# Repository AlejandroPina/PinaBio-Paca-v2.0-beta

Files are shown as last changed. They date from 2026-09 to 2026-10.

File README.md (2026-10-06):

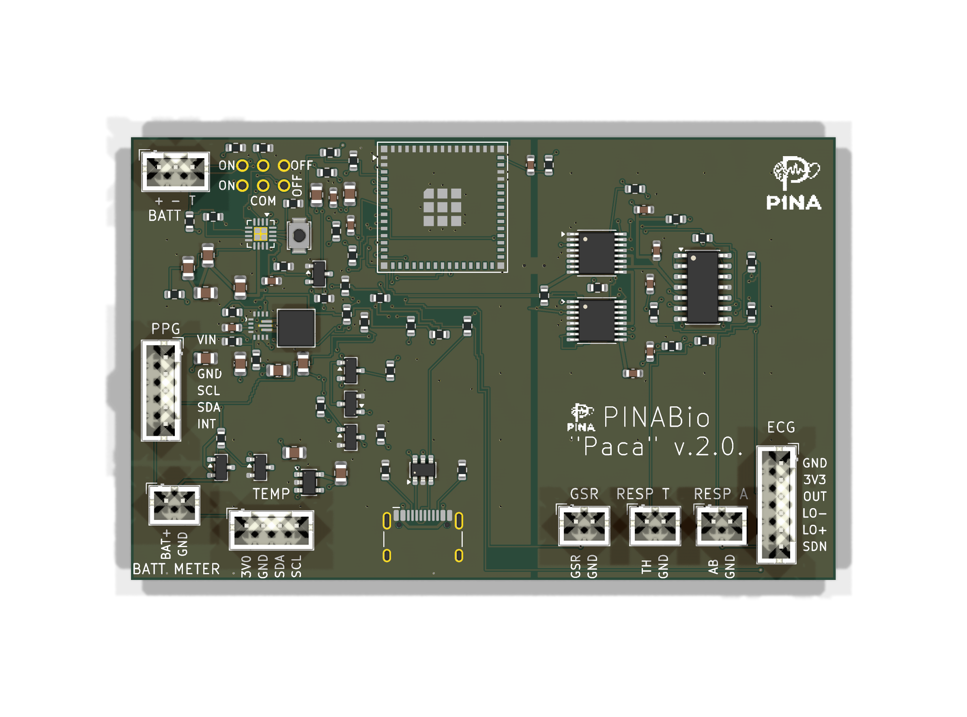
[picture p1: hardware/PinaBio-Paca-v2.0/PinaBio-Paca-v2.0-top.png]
PinaBio Paca v.2.0., cara superior de la PCB


# PinaBio Paca v2.0 beta

[English](README.en.md)

Placa experimental para registrar ECG, pulso óptico (PPG), respuesta galvánica de la piel (GSR), dos bandas de respiración y temperatura, y transmitir los datos por BLE. El uso previsto es investigación y biofeedback; no es un dispositivo médico.

La nueva placa **PINABio "Paca" v.2.0.** se encuentra en [hardware/PinaBio-Paca-v2.0](hardware/PinaBio-Paca-v2.0/README.md). Es un proyecto editable de **KiCad 9.0.9**, con esquemático, PCB de cuatro capas, BOM, Gerbers, taladros y posiciones. Mide **84,50 × 53,11 mm**. KiCad 9.0.9 informa **ERC 0, DRC 0, 0 conexiones pendientes y 0 diferencias entre esquemático y PCB**. Los archivos de fabricación son una salida de prototipo; falta la inspección independiente de huellas y la validación eléctrica de la primera placa ensamblada.

## Qué lleva

- ESP32-S3-MINI-1U-N8 con antena externa U.FL, BLE y Wi-Fi desactivado.
- Dos ADS122C04: uno dedicado al ECG a 600 SPS y otro para GSR, respiración torácica, respiración abdominal y AUX.
- MCP6004, módulo AD8232 externo, módulo GY-MAX30102 externo y módulo CJMCU-30205 externo.
- LiPo protegida de una celda, BQ24074 con power-path, TPS63070 para 3V3_SYS y TLV75530PDBVR a 3,0 V solo para la temperatura.
- Un USB-C soldado en el borde para carga, programación y datos. El interruptor exterior DPDT ON-ON controla el modo del BQ24074 y la habilitación del TPS63070. Con ON y USB, el sistema funciona desde la batería y no carga.
- No hay cortes automáticos en los sensores ni aislamiento USB en la placa. Para adquirir con una persona conectada y USB presente se requiere un aislador USB externo apto para ese uso.

## Documentación

- [Proyecto y conexiones de la PCB](hardware/PinaBio-Paca-v2.0/README.md)
- [Especificación de hardware](docs/es/especificacion.md)
- [Alimentación y USB](docs/es/alimentacion-usb.md)
- [Protocolo y datos](docs/es/protocolo.md)
- [Comparación con V1](docs/es/comparacion-v1.md)

**Antes de encargar montaje:** confirmar orientación y dimensiones del USB-C, TPS63070, todos los conectores y el interruptor cableado; medir los tres módulos externos reales; verificar las transiciones ON/OFF/USB y las tensiones del cargador y reguladores. Los informes de KiCad no sustituyen estas pruebas.

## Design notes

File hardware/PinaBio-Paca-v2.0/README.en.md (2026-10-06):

PinaBio Paca v.2.0. PCB top view

# PINABio "Paca" v.2.0.

[Español](README.md) · [Full specification](../../docs/en/specification.md) · [Power and USB](../../docs/en/power-usb.md)

Editable **KiCad 9.0.9** project, four layers, **84.50 × 53.11 mm**. It implements the project's fixed architecture: one soldered USB-C, physical-switch-controlled BQ24074 standby, no VBUS cut-off MOSFET, two regulators, no automatic sensor disconnects or new I²C pull-ups, two ground regions joined only at NT1, and a copper keepout on all layers beneath the ESP32 U.FL end. The TPS63070 and inductor keep SW_L1 and SW_L2 entirely on F.Cu at 0.40 mm with no vias; the RNM footprint retains pin 1 at top left and counterclockwise numbering.

## Files and checks

- `PinaBio-Paca-v2.0.kicad_sch`, `.kicad_pcb`, `.kicad_pro`: editable schematic and PCB.
- `PinaBio.kicad_sym`, `lib.pretty/`, `sym-lib-table`, `fp-lib-table`: required libraries.
- `bom.csv`: parts list with manufacturer part numbers. L1 is **Coilcraft XAL4020-152MEC**.
- `fab/`: four-layer copper, mask, paste, silkscreen and outline Gerbers; separate PTH/NPTH drill files; `position.csv` in millimetres. `PinaBio-Paca-v2.0-Gerbers.zip` bundles the 14 board and drill files for fabrication upload; BOM and placement are separate.
- `final-erc.txt`, `final-parity.txt`: **ERC 0, DRC 0, 0 unrouted connections and schematic/PCB parity 0**, checked with KiCad 9.0.9.
- `Logo PINA-reducido.jfif`: source image converted to one-colour board silkscreen.

These Gerbers are **prototype outputs**. Before fabrication or assembly, independently check footprints against purchased parts and test one assembled unit, particularly USB-C and TPS63070 orientation, ON/OFF/USB transitions and external-module wiring.

## Connector map

| Ref | Pins in order |
|---|---|
| J1 | HCTL HC-TYPE-C-16P-01A USB-C at lower edge; D+ and D− via USBLC6-2SC6 and 22 Ω series resistors. |
| J2 BATT | 1 protected BAT+, 2 GND, 3 TS/NTC. Three-pin JST PH. The silkscreen says “BATT” below the connector. |
| J3 ECG | 1 AGND, 2 3V3_A, 3 ECG_OUT, 4 LO_N, 5 LO_P, 6 3V3_A (SDN permanently enabled). Matches the red module order GND, 3.3V, OUTPUT, LO−, LO+, SDN. |
| J4 PPG | 1 3V3_SYS/VIN, 2 GND, 3 SCL, 4 SDA, 5 INT. “VIN” identifies module power; the other four signals are labelled by their pins. |
| J5 TEMP | 1 3V0_TEMP, 2 GND, 3 SDA, 4 SCL. Four-pin JST PH; tie A0/A1/A2 to GND on the CJMCU-30205 module. |
| J6 GSR | 1 GSR signal, 2 AGND. |
| J7 RESP T | 1 chest signal, 2 AGND. |
| J8 RESP A | 1 abdominal signal, 2 AGND. |
| J9 BATT METER | 1 switched BAT+, 2 GND. JST PH B2B-PH-K-S(LF)(SN), reserved for the battery meter. |

J9 is live only while **3V3_SYS** is active (ON with battery, or OFF with USB). Q4 BSS84 and Q5 BSS138 form the high-side switch; Q4 has 1 MΩ gate-to-source. J9 is not a general power output.

## Switch and power

SW1 is **six cable holes**, not a footprint for soldering the switch. The reference panel part is C&K **7201SYZQE**, DPDT ON-ON. Another six-terminal DPDT ON-ON part, such as an MTS-202, may be used after checking its common terminals and contact states with a meter. Hole 1–6 numbering follows C&K terminal 1–6: 1 VLOG, 2 EN2_CE, 3 GND, 4 BAT_PROT, 5 TPS_EN, 6 VLOG.

R39, **10 kΩ, 1 %**, sits close to TPS63070 EN, between TPS_EN and TPS_EN_IC. R12, 100 kΩ, stays on the switch side. PS/SYNC is tied to ground for forced PWM. TLV75530PDBVR supplies **only** the temperature module at 3.0 V. VBUS link R3 remains **0 Ω**.

With OFF and USB attached, the battery charges and the board may be programmed. With ON and USB attached, BQ24074 is in standby: the LiPo runs the board, USB carries data, and charging stops. A suitable external USB isolator is required before connecting a person in that state. The PCB has no onboard isolation or automatic sensor disconnect.

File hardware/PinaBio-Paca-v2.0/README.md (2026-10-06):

PCB PinaBio Paca v.2.0., cara superior

# PINABio "Paca" v.2.0.

[English](README.en.md) · [Especificación completa](../../docs/es/especificacion.md) · [Alimentación y USB](../../docs/es/alimentacion-usb.md)

Proyecto editable de **KiCad 9.0.9**, cuatro capas, **84,50 × 53,11 mm**. Implementa la arquitectura cerrada del proyecto: un USB-C soldado, BQ24074 en standby mediante interruptor exterior, sin MOSFET de corte de VBUS, dos reguladores, sin cortes automáticos de sensores ni pull-ups nuevos de I²C, dos masas unidas solo en NT1 y keepout de cobre en todas las capas bajo el extremo U.FL del ESP32. La zona del TPS63070 y la bobina mantiene los nodos SW_L1 y SW_L2 en F.Cu, 0,40 mm y sin vías; la huella RNM conserva el pin 1 arriba a la izquierda y la numeración antihoraria.

## Archivos y verificación

- `PinaBio-Paca-v2.0.kicad_sch`, `.kicad_pcb` y `.kicad_pro`: esquemático y PCB.
- `PinaBio.kicad_sym`, `lib.pretty/`, `sym-lib-table` y `fp-lib-table`: bibliotecas necesarias.
- `bom.csv`: lista de materiales con MPN. L1 es **Coilcraft XAL4020-152MEC**.
- `fab/`: Gerbers de las cuatro capas, máscaras, pasta, serigrafía, contorno, taladros PTH/NPTH y `position.csv` en milímetros. `PinaBio-Paca-v2.0-Gerbers.zip` agrupa los 14 archivos de placa y taladro para subirlos al fabricante; BOM y posiciones se entregan por separado.
- `final-erc.txt` y `final-parity.txt`: **ERC 0, DRC 0, 0 sin conectar y paridad esquema-PCB 0**, ejecutados con KiCad 9.0.9.
- `Logo PINA-reducido.jfif`: imagen fuente del logo que se convirtió a serigrafía monocroma.

Los Gerbers son **de prototipo**. Antes de fabricar o montar, otra persona debe cotejar las huellas con los componentes comprados y ensayar una primera unidad, en especial la orientación del USB-C y TPS63070, las transiciones ON/OFF/USB y el cableado de los módulos externos.

## Conectores

| Referencia | Conexión por orden de pin |
|---|---|
| J1 | USB-C HCTL HC-TYPE-C-16P-01A, boca en el borde inferior; D+ y D− pasan por USBLC6-2SC6 y resistencias de 22 Ω. |
| J2 BATT | 1 BAT+ protegido, 2 GND, 3 TS/NTC. JST PH de 3 pines. La serigrafía usa «BATT» debajo del conector. |
| J3 ECG | 1 AGND, 2 3V3_A, 3 ECG_OUT, 4 LO_N, 5 LO_P, 6 3V3_A (SDN permanentemente habilitado). Orden del módulo rojo: GND, 3.3V, OUTPUT, LO−, LO+, SDN. |
| J4 PPG | 1 3V3_SYS/VIN, 2 GND, 3 SCL, 4 SDA, 5 INT. «VIN» identifica la alimentación del módulo; las otras cuatro señales están rotuladas junto a sus pines. |
| J5 TEMP | 1 3V0_TEMP, 2 GND, 3 SDA, 4 SCL. JST PH de 4 pines; unir A0/A1/A2 a GND en el módulo CJMCU-30205. |
| J6 GSR | 1 señal GSR, 2 AGND. |
| J7 RESP T | 1 señal torácica, 2 AGND. |
| J8 RESP A | 1 señal abdominal, 2 AGND. |
| J9 BATT METER | 1 BAT+ conmutado por Q4 BSS84/Q5 BSS138, 2 GND. JST PH B2B-PH-K-S(LF)(SN), reservado para el medidor de batería. |

J9 solo entrega tensión cuando está activo **3V3_SYS** (ON con batería u OFF con USB). Q4 tiene una resistencia de 1 MΩ entre puerta y fuente. La alimentación del medidor procede de BAT_PROT y no está destinada a alimentar otros módulos.

## Interruptor y alimentación

SW1 son **seis taladros para cable**, no una huella para soldar el interruptor. La pieza de referencia en la caja es C&K **7201SYZQE**, DPDT ON-ON. Puede emplearse otro DPDT ON-ON de seis terminales, como un MTS-202, después de verificar con multímetro sus comunes y contactos. Taladros 1–6 corresponden a terminales 1–6 de la referencia C&K: 1 VLOG, 2 EN2_CE, 3 GND, 4 BAT_PROT, 5 TPS_EN y 6 VLOG.

R39 de **10 kΩ, 1 %**, junto al pin EN del TPS63070, separa TPS_EN de TPS_EN_IC. R12 de 100 kΩ queda al lado del interruptor. PS/SYNC va a masa para PWM forzado. El TLV75530PDBVR alimenta **solo** el módulo de temperatura a 3,0 V; R3 de VBUS continúa en **0 Ω**.

Con OFF y USB se carga la batería y la placa puede programarse. Con ON y USB el BQ24074 está en standby: el sistema se alimenta de la LiPo, USB lleva datos y la batería no carga. Para conectar a una persona en ese modo se exige un aislador USB externo apropiado. No hay aislador ni desconexión automática de sensores en la PCB.

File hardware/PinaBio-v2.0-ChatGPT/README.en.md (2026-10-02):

PinaBio Paca v.2.0. PCB top view

# PINABio "Paca" v.2.0. — ChatGPT board

[Español](README.md) · [Full specification](../../docs/en/specification.md) · [Power and USB](../../docs/en/power-usb.md)

Editable **KiCad 9.0.9** project, four layers, **84.50 × 53.11 mm**. Derived from the Cursor implementation while retaining its fixed architecture: one soldered USB-C, physical-switch-controlled BQ24074 standby, no VBUS cut-off MOSFET, two regulators, no automatic sensor disconnects or new I²C pull-ups, two ground regions joined only at NT1, and a copper keepout on all layers beneath the ESP32 U.FL end. The TPS63070 and inductor keep SW_L1 and SW_L2 entirely on F.Cu at 0.40 mm with no vias; the RNM footprint retains pin 1 at top left and counterclockwise numbering.

## Files and checks

- `PinaBio-v2.0-ChatGPT.kicad_sch`, `.kicad_pcb`, `.kicad_pro`: editable schematic and PCB.
- `PinaCursor.kicad_sym`, `lib.pretty/`, `sym-lib-table`, `fp-lib-table`: required libraries.
- `bom.csv`: parts list with manufacturer part numbers. L1 is **Coilcraft XAL4020-152MEC**.
- `fab/`: four-layer copper, mask, paste, silkscreen and outline Gerbers; separate PTH/NPTH drill files; `position.csv` in millimetres. `PinaBio-v2.0-ChatGPT-Gerbers.zip` bundles the 14 board and drill files for fabrication upload; BOM and placement are separate.
- `final-erc.txt`, `final-parity.txt`: **ERC 0, DRC 0, 0 unrouted connections and schematic/PCB parity 0**, checked with KiCad 9.0.9.
- `Logo PINA-reducido.jfif`: source image converted to one-colour board silkscreen.

These Gerbers are **prototype outputs**. Before fabrication or assembly, independently check footprints against purchased parts and test one assembled unit, particularly USB-C and TPS63070 orientation, ON/OFF/USB transitions and external-module wiring.

## Connector map

| Ref | Pins in order |
|---|---|
| J1 | HCTL HC-TYPE-C-16P-01A USB-C at lower edge; D+ and D− via USBLC6-2SC6 and 22 Ω series resistors. |
| J2 BATT | 1 protected BAT+, 2 GND, 3 TS/NTC. Three-pin JST PH. The silkscreen says “BATT” below the connector. |
| J3 ECG | 1 AGND, 2 3V3_A, 3 ECG_OUT, 4 LO_N, 5 LO_P, 6 3V3_A (SDN permanently enabled). Matches the red module order GND, 3.3V, OUTPUT, LO−, LO+, SDN. |
| J4 PPG | 1 3V3_SYS/VIN, 2 GND, 3 SCL, 4 SDA, 5 INT. “VIN” identifies module power; the other four signals are labelled by their pins. |
| J5 TEMP | 1 3V0_TEMP, 2 GND, 3 SDA, 4 SCL. Four-pin JST PH; tie A0/A1/A2 to GND on the CJMCU-30205 module. |
| J6 GSR | 1 GSR signal, 2 AGND. |
| J7 RESP T | 1 chest signal, 2 AGND. |
| J8 RESP A | 1 abdominal signal, 2 AGND. |
| J9 BATT METER | 1 switched BAT+, 2 GND. JST PH B2B-PH-K-S(LF)(SN), for a meter drawing only tens of mA. |

J9 is live only while **3V3_SYS** is active (ON with battery, or OFF with USB). Q4 BSS84 and Q5 BSS138 form the high-side switch; Q4 has 1 MΩ gate-to-source. J9 is not a general power output.

## Switch and power

SW1 is **six cable holes**, not a footprint for soldering the switch. The reference panel part is C&K **7201SYZQE**, DPDT ON-ON. Another six-terminal DPDT ON-ON part, such as an MTS-202, may be used after checking its common terminals and contact states with a meter. Hole 1–6 numbering follows C&K terminal 1–6: 1 VLOG, 2 EN2_CE, 3 GND, 4 BAT_PROT, 5 TPS_EN, 6 VLOG.

R39, **10 kΩ, 1 %**, sits close to TPS63070 EN, between TPS_EN and TPS_EN_IC. R12, 100 kΩ, stays on the switch side. PS/SYNC is tied to ground for forced PWM. TLV75530PDBVR supplies **only** the temperature module at 3.0 V. VBUS link R3 remains **0 Ω**.

With OFF and USB attached, the battery charges and the board may be programmed. With ON and USB attached, BQ24074 is in standby: the LiPo runs the board, USB carries data, and charging stops. A suitable external USB isolator is required before connecting a person in that state. The PCB has no onboard isolation or automatic sensor disconnect.

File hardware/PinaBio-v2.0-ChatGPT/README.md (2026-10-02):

PCB PinaBio Paca v.2.0., cara superior

# PINABio "Paca" v.2.0. — placa ChatGPT

[English](README.en.md) · [Especificación completa](../../docs/es/especificacion.md) · [Alimentación y USB](../../docs/es/alimentacion-usb.md)

Proyecto editable de **KiCad 9.0.9**, cuatro capas, **84,50 × 53,11 mm**. Deriva de la implementación de Cursor y conserva su arquitectura: un USB-C soldado, BQ24074 en standby mediante interruptor exterior, sin MOSFET de corte de VBUS, dos reguladores, sin cortes automáticos de sensores ni pull-ups nuevos de I²C, dos masas unidas solo en NT1 y keepout de cobre en todas las capas bajo el extremo U.FL del ESP32. La zona del TPS63070 y la bobina mantiene los nodos SW_L1 y SW_L2 en F.Cu, 0,40 mm y sin vías; la huella RNM conserva el pin 1 arriba a la izquierda y la numeración antihoraria.

## Archivos y verificación

- `PinaBio-v2.0-ChatGPT.kicad_sch`, `.kicad_pcb` y `.kicad_pro`: esquemático y PCB.
- `PinaCursor.kicad_sym`, `lib.pretty/`, `sym-lib-table` y `fp-lib-table`: bibliotecas necesarias.
- `bom.csv`: lista de materiales con MPN. L1 es **Coilcraft XAL4020-152MEC**.
- `fab/`: Gerbers de las cuatro capas, máscaras, pasta, serigrafía, contorno, taladros PTH/NPTH y `position.csv` en milímetros. `PinaBio-v2.0-ChatGPT-Gerbers.zip` agrupa los 14 archivos de placa y taladro para subirlos al fabricante; BOM y posiciones se entregan por separado.
- `final-erc.txt` y `final-parity.txt`: **ERC 0, DRC 0, 0 sin conectar y paridad esquema-PCB 0**, ejecutados con KiCad 9.0.9.
- `Logo PINA-reducido.jfif`: imagen fuente del logo que se convirtió a serigrafía monocroma.

Los Gerbers son **de prototipo**. Antes de fabricar o montar, otra persona debe cotejar las huellas con los componentes comprados y ensayar una primera unidad, en especial la orientación del USB-C y TPS63070, las transiciones ON/OFF/USB y el cableado de los módulos externos.

## Conectores

| Referencia | Conexión por orden de pin |
|---|---|
| J1 | USB-C HCTL HC-TYPE-C-16P-01A, boca en el borde inferior; D+ y D− pasan por USBLC6-2SC6 y resistencias de 22 Ω. |
| J2 BATT | 1 BAT+ protegido, 2 GND, 3 TS/NTC. JST PH de 3 pines. La serigrafía usa «BATT» debajo del conector. |
| J3 ECG | 1 AGND, 2 3V3_A, 3 ECG_OUT, 4 LO_N, 5 LO_P, 6 3V3_A (SDN permanentemente habilitado). Orden del módulo rojo: GND, 3.3V, OUTPUT, LO−, LO+, SDN. |
| J4 PPG | 1 3V3_SYS/VIN, 2 GND, 3 SCL, 4 SDA, 5 INT. «VIN» identifica la alimentación del módulo; las otras cuatro señales están rotuladas junto a sus pines. |
| J5 TEMP | 1 3V0_TEMP, 2 GND, 3 SDA, 4 SCL. JST PH de 4 pines; unir A0/A1/A2 a GND en el módulo CJMCU-30205. |
| J6 GSR | 1 señal GSR, 2 AGND. |
| J7 RESP T | 1 señal torácica, 2 AGND. |
| J8 RESP A | 1 señal abdominal, 2 AGND. |
| J9 BATT METER | 1 BAT+ conmutado por Q4 BSS84/Q5 BSS138, 2 GND. JST PH B2B-PH-K-S(LF)(SN), solo para medidor de unas decenas de mA. |

J9 solo entrega tensión cuando está activo **3V3_SYS** (ON con batería u OFF con USB). Q4 tiene una resistencia de 1 MΩ entre puerta y fuente. La alimentación del medidor procede de BAT_PROT y no está destinada a alimentar otros módulos.

## Interruptor y alimentación

SW1 son **seis taladros para cable**, no una huella para soldar el interruptor. La pieza de referencia en la caja es C&K **7201SYZQE**, DPDT ON-ON. Puede emplearse otro DPDT ON-ON de seis terminales, como un MTS-202, después de verificar con multímetro sus comunes y contactos. Taladros 1–6 corresponden a terminales 1–6 de la referencia C&K: 1 VLOG, 2 EN2_CE, 3 GND, 4 BAT_PROT, 5 TPS_EN y 6 VLOG.

R39 de **10 kΩ, 1 %**, junto al pin EN del TPS63070, separa TPS_EN de TPS_EN_IC. R12 de 100 kΩ queda al lado del interruptor. PS/SYNC va a masa para PWM forzado. El TLV75530PDBVR alimenta **solo** el módulo de temperatura a 3,0 V; R3 de VBUS continúa en **0 Ω**.

Con OFF y USB se carga la batería y la placa puede programarse. Con ON y USB el BQ24074 está en standby: el sistema se alimenta de la LiPo, USB lleva datos y la batería no carga. Para conectar a una persona en ese modo se exige un aislador USB externo apropiado. No hay aislador ni desconexión automática de sensores en la PCB.

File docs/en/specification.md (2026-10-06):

# PinaBio Paca v2.0 beta — hardware specification `SPEC-0.9`

This design specification now has a KiCad 9.0.9 prototype implementation. ERC, DRC and schematic/PCB parity are zero; independent footprint review and tests on an assembled board are still required. PinaBio is for experimental research and biofeedback, not medical use or diagnosis.

## Scope and power architecture

The ESP32-S3-MINI-1U-N8 acquires ECG, PPG, GSR, thoracic and abdominal respiration bands, local temperature and battery voltage, then sends raw data over BLE with Wi‑Fi disabled. One ADS122C04 is dedicated to ECG; the other serves GSR and both bands. MAX30102 and MAX30205 are external I²C modules.

LiPo 1S protected → BQ24074 → TPS63070 → nominal 3.295 V `3V3_SYS` (49.9 kΩ / 16.0 kΩ, 0.1 %, forced PWM). An initially 0 Ω link may feed a `3V3_A` analogue island. A TLV75530PDBVR makes `3V0_TEMP` only for the CJMCU-30205, with 2.2 µF X7R 0805 at input and output. There is **no 2.9 V rail, TPS7A20 or TCA9801**.

## USB, switch and body connections

USB-C is a USB 2.0 sink: CC1/CC2 have 5.1 kΩ Rd resistors. D+ and D− pass through a USBLC6-2SC6 in SOT-23-6 (the same pinout as the USBLC6-2P6: connector on one side, ESP32 on the other, GND and VBUS as on that symbol) and then through 22 Ω in series: D− to GPIO19 and D+ to GPIO20. Protected VBUS reaches BQ24074 IN in both switch positions. There is no external VBUS-cutoff MOSFET. The physical switch sets the charger mode pins and regulator enable independently of the ESP32.

The switch is not on the board: it mounts in the enclosure. The part is a C&K 7201SYZQE (7000 series, DPDT, two maintained ON-ON positions, threaded panel bushing, six solder-lug terminals). It is not momentary, not a three-position switch, and it is not the JS202011JCQN. The datasheet is *7000 Series Miniature Toggle Switches* ([PDF](https://media.digikey.com/pdf/Data%20Sheets/C&K/7000%20Mini%20Toggle%20Series.pdf)); the DPDT figure on page 2 names 7201SYZQE. The code reads: 7201 = DP On-None-On, S = 0.420 in actuator, Y = 0.350 in bushing with keyway and 1/4-40 thread, Z = six solder lugs, Q = contact material, E = epoxy seal. Commons are terminals 2 and 5. ON is the lever away from the keyway (datasheet position 3): it closes 2-1 and 5-4. OFF is the lever toward the keyway (position 1): it closes 2-3 and 5-6. The cable is one-to-one: board pad 1 `VLOG` to terminal 1, pad 2 `EN2_CE` to terminal 2, pad 3 `GND` to terminal 3, pad 4 `BAT_PROT` to terminal 4, pad 5 `TPS_EN` to terminal 5, and pad 6 `VLOG` to terminal 6. ON therefore ties `EN2_CE` to `VLOG` and `TPS_EN` to `BAT_PROT`; OFF ties `EN2_CE` to `GND` and `TPS_EN` to `VLOG`. The six board holes have no orderable code; the code belongs to the enclosure switch.

With OFF and valid VBUS, `EN1=high`, `EN2=low` and `CE=low` allow charging and USB-powered OUT; USB500 is permitted only when the source supports that current. With ON and valid VBUS, `EN1=EN2=high` select standby/USB suspend: internal `Q1` (IN→OUT) is open, `Q2` (BAT→OUT) is closed and charging stops. `CE=high` adds charge inhibition but cannot alone prevent USB from powering OUT. EN1, EN2 and CE must be driven by the physical switch and VBUS, remain defined with no battery, and never rely on firmware. ILIM, ISET and ITERM are sized for the actual USB source, cell and initial ≈300 mA charge target. TMR is 46.4 kΩ, 1 %, to ground. TS connects to the cell NTC. GPIO0 is reserved for BOOT, with a 10 kΩ pull-up to `3V3_SYS`; the BOOT button takes it to ground.

The VBUS-derived logic must meet these limits at each EN1, EN2 and CE pin: low **0–0.4 V**, high **1.4–6 V**, absolute maximum **−0.3 to 7 V**, including transients. The schematic must provide the necessary voltage limiting/protection and operating margin below 6 V; 7 V is not a design target. The higher voltage tolerance at IN does not extend to these pins. See [power and USB](power-usb.md).

The TPS63070 hardware enable must implement `(OFF and valid VBUS) or (ON and valid battery)`. This permits OFF+USB programming without a battery while preventing ON+USB from starting without one. The schematic must define the battery-valid condition and verify source transitions on an ON→OFF switch movement. [TI BQ24074 datasheet](https://www.ti.com/lit/ds/symlink/bq24074.pdf), Table 7-2 and Section 9.3.2.

| Switch | USB | BQ24074 mode | Board source | LiPo charge | USB data | Person-connected use |
|---|---:|---|---|---|---|---|
| OFF | no | invalid input | none | no | no | no acquisition |
| OFF | yes | USB500 if source permits | USB through BQ24074 | yes | yes, programming | no person connected |
| ON | no | invalid input | LiPo | no | no | battery acquisition |
| ON | yes | standby, `EN1=EN2=high` | LiPo | no | yes | external USB isolator required |

With OFF, USB powers the ESP for programming and charges the cell; removing USB powers the board down. With ON, D+/D− remain available and OUT is battery powered even though VBUS remains at charger IN. ECG, PPG, temperature, GSR and respiration connectors connect directly to their respective front ends, without automatic cutoff relays or switches. OFF+USB can therefore energize sensor connectors; direct-USB charging and programming require removing all sensors from the person.

An external host-powered USB isolator is mandatory for use with a person while USB is connected. The board USB ground is not cut; isolation belongs in the external cable. Firmware can report USB presence but cannot prove that an isolator is fitted. A normal USB cable must not be used on a person.

## Acquisition front ends

| Signal | Implementation and initial configuration |
|---|---|
| ECG | External AD8232, dedicated ADS122C04, internal 2.048 V reference, PGA bypass, gain 1, 600 SPS. Divider: 33.2 kΩ from OUTPUT and 47.5 kΩ to ground, 1 %. At a 3.30 V full-scale output the ADC sees 1.94 V; at 3.40 V it sees 2.00 V, under the 2.048 V reference. Do not use 20.0/40.2 kΩ. Measure the real swing to confirm the module does not clip before the divider. A divider cannot repair an OUTPUT that is already clipped. |
| GSR | MCP6004-buffered ≈0.50 V excitation; a physical 100 kΩ series resistor limits normal short-circuit current to ≈5 µA. |
| Thorax / abdomen | One identical buffered front end each; measure real band ranges before freezing 100 kΩ and filters. |
| PPG | External MAX30102/GY-30102, 3.3 V, I²C plus INT; validate its actual regulators, pull-ups, LED current and voltage levels. |
| Temperature | CJMCU-30205 from `3V0_TEMP` only, on a 4-pin connector (3V0_TEMP, GND, SDA, SCL). Module VCC ties straight to the chip. A0, A1 and A2 of the module are tied to GND on the module itself (solder or a short wire), not through the cable, and set address 0x48. The module's OS is left unconnected (the module carries its own 10 kΩ pull-up). |

The slow ADS initially samples GSR, thorax and abdomen at 20 SPS each. Report OPEN, SHORT, OUT_OF_RANGE and UNCALIBRATED rather than false values. Bands provide resistance and a derived respiratory curve, not lung volume. ADS IDACs remain disabled and never connect to body paths.

## Board

Four layers. The board is **84.50 × 53.11 mm**; the width leaves room for J3 labels outside the connector. USB-C is at the lower edge with its mouth extending past the outline. The ESP32-S3-MINI-1U has no printed antenna: it has a U.FL connector. That end of the module sits at the upper board edge, as far out as it will go, so the external antenna is outside the copper. On every layer, under that end and a little past the module edge outward, there is no copper, no track, no via and no plane. USB and the buck do not sit under that zone.

There are two ground planes. Digital ground covers the ESP32, USB, the BQ24074 and the TPS63070. Analogue ground covers the ADS122C04 devices, the MCP6004, the ECG divider, GSR and the bands. They join in one place, short and wide, next to the ADCs and the 0 Ω link between `3V3_SYS` and `3V3_A`, so the supply and the return meet at the same point. There are no extra joins and no thin track crossing the board. Analogue signals do not cross digital ground. In1 is ground, split into those two zones. F.Cu carries the same split, stitched with vias to its own zone. In2 is `3V3_SYS` and carries no data signals. B.Cu carries the signals.

Both TPS63070 inductor nodes stay on F.Cu, with no via, at 0.40 mm for the whole run.

## Mandatory verification

Measure every breakout; test all four USB/switch states including no battery; prove ON+USB leaves OUT on BAT with zero charge current and VBUS/D+/D− cannot back-power ON-without-battery. Capture EN1, EN2 and CE during steady states and switch/USB transients to check their voltage limits. With OFF+USB, document voltage at the sensor connectors. Measure 3.3 V ripple and load, GSR fault current, ECG range/noise, external buses and USB-isolator behaviour. KiCad 9.0.9 schematic, PCB, BOM, Gerbers, drill and placement outputs exist with ERC, DRC and schematic/PCB parity at zero. Footprint checks, body-connected-path review and these bench results remain necessary before a production order.

## Implementation contract

- J3, external AD8232 module: pin 1 AGND/GND, 2 3V3_A/3.3V, 3 ECG_OUT/OUTPUT, 4 LO_N/LO−, 5 LO_P/LO+, 6 3V3_A/SDN. SDN remains enabled. This matches the red module order for a flat cable.
- J5, CJMCU-30205: pin 1 3V0_TEMP, 2 GND, 3 SDA, 4 SCL. J9 battery meter: JST PH B2B-PH-K-S(LF)(SN), pin 1 switched BAT+, pin 2 GND. A BSS84LT1G high-side device and BSS138LT1G enable it only while 3V3_SYS exists; 1 MΩ ties the BSS84 gate to its source. J9 is reserved for the battery meter.
- R39, YAGEO RC0603FR-0710KL, 10 kΩ 1 %, is in series between TPS_EN and TPS63070 EN, close to the IC. The 100 kΩ R12 pulldown remains on the switch side. PS/SYNC stays grounded. R3 remains 0 Ω.
- L1 is Coilcraft **XAL4020-152MEC**, 1.5 µH with the unchanged XAL4020 footprint; “C” denotes 7-inch reel packaging.
- J3 silkscreen labels form one column outside and aligned with its six pins. The PINA logo remains at the upper right, with a smaller copy beside the two-line “PINABio \"Paca\" v.2.0.” board name at centre right. J2 is marked BATT; J4's VIN, GND, SCL, SDA and INT labels share one left alignment. Connector names and pin labels are at least 1.0 mm high with 0.15 mm stroke.

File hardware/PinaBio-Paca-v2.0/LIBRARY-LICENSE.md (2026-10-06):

The project uses official KiCad symbols and footprints under the [KiCad library license](https://www.kicad.org/libraries/license/). The local `PinaBio.kicad_sym` and `lib.pretty/` contain project-specific ADS122C04/TPS63070 symbols and TPS63070, switch-hole and ground-tie footprints derived from the manufacturers' package and pinout drawings. Check those footprints against the purchased parts before assembly.

The optional `3dmodels/ESP32-S3-MINI-1U.STEP` model was copied from the [Espressif KiCad libraries](https://github.com/espressif/kicad-libraries), licensed CC-BY-SA 4.0 with the electronics-design waiver in the upstream LICENSE.md.

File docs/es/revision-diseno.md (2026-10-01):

# Revisión de diseño — 1 de octubre de 2026

La revisión `SPEC-0.9` / `PWR-0.7` mantiene las decisiones de `SPEC-0.8` y añade el USB, el temporizador del cargador, la antena U.FL y la masa partida. Siguen vigentes los límites de tensión y ensayos de `EN1`, `EN2` y `CE` del BQ24074.

1. El TPS63070 queda a 3,295 V (49,9 kΩ / 16,0 kΩ, 0,1 %, PWM forzado). Un TLV75530PDBVR hace 3,0 V solo para el CJMCU-30205, cuyo VCC entra directo al chip, con 2,2 µF X7R en entrada y salida. No hay raíl de 2,9 V ni TCA9801.
2. OFF permite carga y programación desde USB. Los conectores de sensores no se cortan; se retiran de la persona antes de usar USB directo.
3. ON con USB pone `EN1=EN2=alto` y `CE=alto`: el BQ24074 abre internamente IN→OUT, mantiene BAT→OUT, detiene la carga y conserva D+/D− para datos/programación. VBUS permanece en `IN`; la placa se alimenta de batería.
4. No hay barrera de contactos ni corte automático por VBUS: la adquisición con USB y una persona solo se admite usando un aislador externo alimentado desde el host. La placa informa presencia USB, pero no puede certificar el aislador.
5. El divisor del ECG es 33,2 kΩ desde OUTPUT y 47,5 kΩ a masa, al 1 %. A 3,40 V de salida plena el ADS ve 2,00 V, por debajo de 2,048 V. La medida comprueba que el módulo no recorta antes del divisor.
6. GSR y las bandas conservan excitación ≈0,50 V y 100 kΩ físicamente en serie, con corriente de corto ≈5 µA.
7. El interruptor físico determina los niveles de `EN1`, `EN2`, `CE` y la habilitación del TPS63070, sin firmware y aun sin batería. OFF+USB debe poder programar; ON+USB sin batería no debe arrancar.
8. `EN1`, `EN2` y `CE` tienen alto funcional de 1,4–6 V, bajo de 0–0,4 V y máximo absoluto de −0,3 a 7 V. El esquema debe proteger estas entradas frente a VBUS y sus transitorios; 7 V no es un valor de operación.
9. D− (GPIO19) y D+ (GPIO20) llevan 22 Ω en serie entre un USBLC6-2SC6 (SOT-23-6) y el ESP32. GPIO0 lleva 10 kΩ a `3V3_SYS` y el pulsador de BOOT lo pone a masa. `TMR` del BQ24074 lleva 46,4 kΩ al 1 % a masa. Los 2,2 µF del TLV75530 son X7R 0805.
10. El ESP32-S3-MINI-1U lleva conector U.FL, no antena impresa. Ese extremo queda en el borde. Bajo él, en todas las capas y un poco más allá del módulo, no hay cobre, pistas, vías ni plano. El USB y el buck no van bajo esa zona.
11. Masa digital (ESP32, USB, BQ24074, TPS63070) y masa analógica (ADS122C04, MCP6004, divisor de ECG, GSR y bandas) se unen en un solo punto, corto y ancho, junto a los ADS y al puente de 0 Ω entre `3V3_SYS` y `3V3_A`. Las señales analógicas no cruzan la masa digital. In1 es esa masa partida; In2 es `3V3_SYS` sin señales de datos. Los dos nodos del inductor del TPS63070 van en F.Cu, sin vía, a 0,40 mm.

Quedan pendientes para el esquema y prototipo: polarización y secuencia de los pines de modo del BQ24074, presupuesto de corriente de los módulos, compatibilidad real de sus niveles eléctricos y pruebas del aislador externo. Ningún documento autoriza fabricar hasta superar los ensayos listados en `especificacion.md`.

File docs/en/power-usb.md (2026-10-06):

# Power and USB — revision `PWR-0.7`

[Home](../../README.en.md) · [Hardware specification](specification.md)

One USB-C connector, a protected 1S LiPo, a BQ24074 power path and a TPS63070 at 3.295 V. A TLV75530PDBVR makes 3.0 V only for the CJMCU-30205. The physical switch controls the BQ24074 mode and the regulator enable; firmware does not choose the charging or system power source.

With **OFF and USB**, `EN1=high`, `EN2=low` and `CE=low` select USB500 mode. Valid `IN` powers `OUT` and charges the cell; TPS63070 can power the ESP32 for programming. Sensor connectors are not automatically disconnected; remove sensors from the person before charging or programming with direct USB. Select the 500 mA input limit only when the USB source permits it. The initial battery-charge target is about 300 mA; measure the simultaneous system load during programming.

With **ON and USB**, `EN1=EN2=high` select standby/USB suspend. TI specifies that internal `Q1` (IN→OUT) is off and `Q2` (BAT→OUT) is on: the battery powers the board and charging stops. `CE=high` adds charge inhibition but cannot replace standby because CE alone leaves USB-powered OUT active. VBUS remains at the charger's `IN` pin; “battery only” describes the source of OUT and the board, not a physically unpowered USB connector or charger. Native D+/D− remain available for programming and data.

Without USB, IN is invalid and OUT follows the battery. ON enables TPS63070; OFF disables it. Any USB acquisition with a person connected requires an external host-powered isolator that separates data, ground and power and supplies the appropriate VBUS on the board side.

| Switch | USB | `EN1/EN2/CE` with valid VBUS | OUT source | Charge | ESP32 | Person-connected use |
|---|---|---|---|---|---|---|
| OFF | no | biased low; invalid input | battery, system load disabled | no | off | no acquisition |
| OFF | yes | high/low/low | USB | yes | on for maintenance | no person connected |
| ON | no | invalid input | battery | no | on | battery acquisition |
| ON | yes | high/high/high | battery | no | on, USB data | external isolator required |

## Hardware requirements

- Protected VBUS connects to BQ24074 IN in both switch positions. **Do not fit the external VBUS-cutoff MOSFET.** Place the IN and OUT capacitors required by TI.
- EN1 must be high when VBUS is valid. EN2 and CE must be high with ON and VBUS, low with OFF and VBUS. The physical switch and bias network must establish these levels without the ESP32 or battery; no control input may float. Verify levels and sequencing when USB is inserted and the switch moves.
- For EN1, EN2 and CE, TI specifies a **1.4–6 V** high level, a **0–0.4 V** low level and an **−0.3 to 7 V** absolute-maximum range. The 7 V limit is not a design target. The network deriving these signals from VBUS must limit their voltage during normal operation, insertion and foreseeable overvoltage, with margin below 6 V; do not connect raw VBUS directly without demonstrating compliance. The IN pin has a different, higher absolute maximum that does not protect the logic pins.
- With ON, USB and no battery, standby must prevent OUT from powering the board from USB. The regulator must not start without a valid battery. With OFF, USB and no battery, programming may start.
- Select ILIM, ISET, ITERM and TS for the actual USB source, cell and NTC. TMR is 46.4 kΩ, 1 %, to ground. BQ24074 has no SYSOFF pin and does not replace cell protection.
- No sensor-connector cutoff relays or switches are fitted. OFF+USB may power those connectors from VBUS, so direct-USB charging and programming require all sensors to be removed from the person. ON+USB with a person requires a host-powered external isolator.
- TPS63070 runs in forced PWM. Feedback divider: 49.9 kΩ from VOUT to FB and 16.0 kΩ from FB to ground, both 0.1 %. Setpoint 3.295 V. PS/SYNC tied low. Both inductor nodes stay on the top copper, with no via, at 0.40 mm for the whole run. The TLV75530PDBVR, with 2.2 µF X7R 0805 at input and output, makes 3.0 V only for the CJMCU-30205 VCC. Those capacitors keep at least 0.47 µF of effective capacitance. Start the analogue-island feed with 0 Ω. Analogue ground and digital ground meet at one short, wide point next to that link and the ADCs, so the supply and the return join together. There are no other joins.
- USB-C uses a USBLC6-2SC6 in SOT-23-6 and separate 5.1 kΩ Rd resistors on CC1/CC2. Between the protector and the ESP32, D− (GPIO19) and D+ (GPIO20) each have 22 Ω in series. D+/D− and VBUS detection must not back-power an off ESP32. The external isolator must create its board-side isolated VBUS from the host. GPIO0 has a 10 kΩ pull-up to `3V3_SYS`; the BOOT button takes it to ground.
- R39 (10 kΩ, 1 %, YAGEO RC0603FR-0710KL) is in series and close to TPS63070 EN; the 100 kΩ R12 pulldown remains on the switch side to avoid a permanent divider. L1 is Coilcraft XAL4020-152MEC, 1.5 µH, with the unchanged footprint. J9 provides BAT+ to a meter only while 3V3_SYS is active: Q4 BSS84 high-side, Q5 BSS138 pull-down, and 1 MΩ from Q4 gate to source. R3 remains a 0 Ω VBUS link, not a fuse.

## Acceptance tests

Measure voltage and current at IN, OUT, BAT, 3V3_SYS and USB in all four states. Capture EN1, EN2 and CE with an oscilloscope in steady state and during USB insertion/removal, VBUS disturbances and switch movement; verify functional thresholds and absolute limits. With ON+USB, OUT must track the battery, charge current must be zero, and removing the battery must not start the board through VBUS or D+/D−. With OFF+USB, test charging and programming without a battery and document voltage at the sensor connectors. Measure external-isolator performance, 3.3 V ripple, module current and charger temperature. Test person-connected acquisition with USB only after verifying the external isolator.

[TI BQ24074 datasheet](https://www.ti.com/lit/ds/symlink/bq24074.pdf), Table 7-2 and Section 9.3.2.

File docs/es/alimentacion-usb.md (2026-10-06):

# Alimentación y USB — revisión `PWR-0.7`

[Portada](../../README.md) · [Especificación](especificacion.md)

Hay un USB-C, una LiPo 1S protegida, un BQ24074 con *power-path* y un TPS63070 a 3,295 V y un TLV75530PDBVR a 3,0 V solo para el CJMCU-30205. El interruptor físico gobierna el modo del BQ24074 y la habilitación del regulador; el firmware no decide si se carga la batería o de dónde sale la energía del sistema.

## Funcionamiento

Con **OFF y USB**, `EN1=alto`, `EN2=bajo` y `CE=bajo` seleccionan el modo USB500 del BQ24074. Su entrada `IN` alimenta `OUT` y carga la LiPo; el TPS63070 puede alimentar el ESP32 para programarlo. Los sensores no se desconectan automáticamente: antes de cargar o programar con USB directo se retiran los sensores de la persona. El límite de 500 mA solo debe seleccionarse cuando la fuente USB lo permita; la carga objetivo inicial es de aproximadamente 300 mA y se debe verificar el consumo simultáneo durante la programación.

Con **ON y USB**, `EN1=EN2=alto` seleccionan *standby/USB suspend*. Según la hoja de datos del BQ24074, el FET interno `Q1` entre `IN` y `OUT` queda abierto y `Q2` entre `BAT` y `OUT` queda cerrado: la LiPo alimenta la placa y no se carga. `CE=alto` añade una inhibición de carga, pero no sustituye `EN1=EN2=alto`, porque `CE` por sí solo deja activa la salida alimentada desde USB. VBUS sigue presente en `IN`; la afirmación «solo batería» se refiere a la alimentación de `OUT` y de la placa, no a que el cargador quede físicamente sin tensión. D+/D− permiten programación y datos.

Sin USB, `IN` no es válido y `OUT` recibe energía de la batería. ON habilita el TPS63070; OFF lo mantiene apagado. Para adquirir con USB y una persona conectada es obligatorio un aislador externo que separe datos, masa y alimentación del ordenador y que proporcione el VBUS necesario del lado de la placa.

| Interruptor | USB | `EN1/EN2/CE` con VBUS válido | Origen de `OUT` | Carga | ESP32 | Uso con persona |
|---|---|---|---|---|---|---|
| OFF | no | bajos por polarización; entrada inválida | batería, sin carga del sistema | no | apagado | sin adquisición |
| OFF | sí | alto/bajo/bajo | USB | sí | encendido para mantenimiento | sin persona conectada |
| ON | no | entrada inválida | batería | no | encendido | adquisición con batería |
| ON | sí | alto/alto/alto | batería | no | encendido, USB datos | solo con aislador externo |

## Implementación obligatoria

- VBUS, después de protección de entrada, llega a `IN` del BQ24074 en ambas posiciones. **No se monta el MOSFET de corte de VBUS.** La entrada `IN` y `OUT` deben tener los condensadores indicados por TI.
- `EN1` debe estar alto cuando VBUS es válido. `EN2` y `CE` deben estar altos con **ON y VBUS**, y bajos con **OFF y VBUS**. El interruptor físico y la polarización de estas redes deben imponer los estados sin ESP32 ni batería; ningún pin de control puede quedar flotante. Los niveles y la secuencia se verifican también durante la inserción de USB y el cambio de posición.
- Para `EN1`, `EN2` y `CE`, TI especifica nivel alto de **1,4–6 V**, nivel bajo de **0–0,4 V** y máximo absoluto de **−0,3 a 7 V**. Los 7 V son un límite de daño, no una consigna de diseño. La red que obtenga estas señales de VBUS debe limitar su tensión durante funcionamiento normal, inserción y sobretensiones previsibles, con margen respecto a 6 V; no se conectará VBUS directamente sin demostrar que esos límites se cumplen. El pin `IN` admite una tensión máxima absoluta distinta y mayor, que no protege los pines lógicos.
- Con **ON, USB y batería ausente**, `EN1=EN2=alto` debe impedir que `OUT` encienda la placa desde USB. El regulador debe permanecer apagado si no hay batería válida. Con **OFF, USB y batería ausente**, el regulador puede arrancar para programación.
- `ILIM`, `ISET`, `ITERM` y `TS` se dimensionan según hoja de datos, fuente USB, NTC y LiPo reales. `TMR` lleva 46,4 kΩ al 1 % a masa. El BQ24074 no tiene pin `SYSOFF` ni sustituye la protección de la celda.
- No se montan relés ni conmutadores de corte en los conectores de sensores. OFF+USB puede alimentar esos conectores desde VBUS; por eso la carga y programación con USB directo se hacen sin persona conectada. ON+USB con persona exige aislador externo alimentado desde el host.
- TPS63070 en PWM forzado. Divisor de FB: 49,9 kΩ de VOUT a FB y 16,0 kΩ de FB a masa, al 0,1 %. Consigna 3,295 V. PS/SYNC a masa. Los dos nodos del inductor van en la capa superior, sin vía, a 0,40 mm en todo el tramo. El TLV75530PDBVR, con 2,2 µF X7R 0805 a la entrada y 2,2 µF X7R 0805 a la salida, hace 3,0 V solo para el VCC del CJMCU-30205. Esos condensadores dejan al menos 0,47 µF efectivos.
- R39 (10 kΩ, 1 %, YAGEO RC0603FR-0710KL) está en serie y junto al pin EN del TPS63070; R12 (100 kΩ a masa) queda del lado del interruptor para evitar un divisor permanente. L1 es Coilcraft XAL4020-152MEC, 1,5 µH, con la misma huella. J9 entrega BAT+ a un medidor solo cuando 3V3_SYS está activo: Q4 BSS84 de lado alto, Q5 BSS138 a masa y 1 MΩ entre puerta y fuente de Q4. R3 continúa como puente de 0 Ω en VBUS; no es un fusible.
- La isla analógica empieza con 0 Ω y se decide si lleva ferrita tras medir ruido. La masa analógica y la masa digital se unen en un solo punto, corto y ancho, junto a ese puente y a los ADS, para que alimentación y retorno coincidan. No hay más uniones.
- USB-C usa un USBLC6-2SC6 en SOT-23-6 y dos resistencias `Rd` de 5,1 kΩ en CC1/CC2. Entre el protector y el ESP32, D− (GPIO19) y D+ (GPIO20) llevan 22 Ω en serie. D+/D− y la detección de VBUS no deben realimentar el ESP32 apagado. El aislador no está soldado a la placa y debe generar su VBUS aislado desde el host. GPIO0 lleva 10 kΩ a `3V3_SYS`; el pulsador de BOOT lo pone a masa.

## Ensayos

Medir tensión y corriente en `IN`, `OUT`, `BAT`, `3V3_SYS` y USB durante los cuatro estados. Registrar con osciloscopio los niveles de `EN1`, `EN2` y `CE` en estado estable y durante inserción, retirada y perturbaciones de VBUS y cambios del interruptor; verificar tanto los umbrales funcionales como los límites absolutos. Con ON+USB, `OUT` debe seguir a la batería, la corriente de carga debe ser nula y quitar la batería no debe arrancar la placa desde VBUS o D+/D−. Con OFF+USB, verificar carga y programación incluso sin batería y documentar la tensión presente en los conectores de sensores. Medir aislamiento del cable externo, rizado de 3,3 V, consumo de módulos y temperatura del cargador. La adquisición con una persona y USB se ensaya solo tras verificar el aislador externo.

[BQ24074, hoja de datos de TI](https://www.ti.com/lit/ds/symlink/bq24074.pdf), tabla 7-2 y apartado 9.3.2.

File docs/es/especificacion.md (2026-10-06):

# PinaBio Paca v2.0 beta — especificación de hardware `SPEC-0.9`

[Portada](../../README.md) · [Alimentación y USB](alimentacion-usb.md) · [Protocolo](protocolo.md)

**Estado:** especificación de diseño con una implementación de prototipo en KiCad 9.0.9. ERC, DRC y paridad esquemático-PCB son cero; faltan revisión independiente de huellas y pruebas de una placa montada. Uso experimental y de biofeedback, no médico. **DEBE** expresa un requisito de diseño; *propuesto* exige comprobación de banco.

## 1. Alcance y arquitectura

PinaBio registra ECG, PPG, GSR, dos bandas de respiración, temperatura local y tensión de batería. El ESP32-S3-MINI-1U-N8 coordina dos ADS122C04, los módulos I²C y BLE; Wi‑Fi permanece desactivado. Un ADS se dedica al ECG y el segundo a GSR, tórax y abdomen. La aplicación conserva muestras crudas y calcula métricas derivadas; ninguna señal constituye diagnóstico.

```text
USB-C ─ ESD ─ BQ24074 IN/OUT ─ SYS ─ TPS63070 ─ 3V3_SYS
                   │                       ├─ ESP32-S3 / BLE / ADS122C04 ×2
LiPo 1S protegida ─┘ BAT                   ├─ isla analógica 3V3_A (0 Ω inicial)
                                              └─ TLV75530PDBVR ─ 3V0_TEMP ─ CJMCU-30205

AD8232 ─ ADS ECG (600 SPS)       MAX30102 ─ I²C + INT
GSR / tórax / abdomen ─ MCP6004 ─ ADS lento       MAX30205 ─ I²C
```

El TPS63070, en PWM forzado, genera el raíl de 3,30 V nominales (consigna 3,295 V). `3V3_A` es una isla filtrable desde `3V3_SYS`, inicialmente puenteada con 0 Ω. **No hay regulador de 2,9 V ni TCA9801.** Un segundo regulador, el TLV75530PDBVR, hace 3,0 V fijos y solo alimenta el VCC del CJMCU-30205. El resto de la placa va al raíl de 3,3 V.

## 2. Alimentación y USB

| Red | Origen y destino | Requisito |
|---|---|---|
| `BAT_PROT` | LiPo 1S protegida → BAT del BQ24074 | 3,0–4,2 V; batería con protección y NTC. |
| `VBUS_RAW` | USB-C y R3 de 0 Ω; protección USBLC6-2SC6 en datos | Nunca a GPIO; detección solo telemétrica. R3 no es un fusible. |
| `SYS` | Salida del BQ24074 → TPS63070 | El BQ24074 aporta *power-path*, no 3,3 V regulados. |
| `3V3_SYS` | TPS63070. FB: 49,9 kΩ de VOUT a FB y 16,0 kΩ de FB a masa, ambas al 0,1 %. PS/SYNC a masa. | 3,295 V nominales. ESP32, ADC, PPG, lógica y la entrada del LDO. Diseñar ≥500 mA y medir picos BLE y PPG. |
| `3V3_A` | Desde 3V3_SYS mediante 0 Ω/ferrita opcional | ADS analógico, MCP6004 y AD8232. |
| `3V0_TEMP` | TLV75530PDBVR desde 3V3_SYS. 2,2 µF X7R 0805 en entrada y en salida, para conservar al menos 0,47 µF efectivos. EN unido a su entrada. | Solo el VCC del CJMCU-30205. |
| `0V5_EXC` | MCP6004 desde 56 kΩ/10 kΩ de 3V3_A | ≈0,50 V; calibrar por placa. |

USB-C es un sumidero USB 2.0: `CC1`/`CC2` llevan `Rd=5,1 kΩ` a masa. D+ y D− pasan por un USBLC6-2SC6 en SOT-23-6 (el mismo patillaje que el USBLC6-2P6: el conector a un lado, el ESP32 al otro, GND y VBUS como en ese símbolo) y, entre el protector y el módulo, por 22 Ω en serie: D− a GPIO19 y D+ a GPIO20. El conector nunca recibe VBUS desde la placa. VBUS protegido llega a `IN` del BQ24074 con OFF y con ON; no hay MOSFET externo de corte. El interruptor físico fija los pines de modo del cargador y la habilitación del regulador sin depender del ESP32.

El interruptor no está en la placa: va montado en la caja. La pieza es un C&K 7201SYZQE (serie 7000, DPDT de dos posiciones estables ON-ON, casquillo roscado de panel y seis terminales de soldar). No es momentáneo ni de tres posiciones, y no es el JS202011JCQN. La hoja es *7000 Series Miniature Toggle Switches* ([PDF](https://media.digikey.com/pdf/Data%20Sheets/C&K/7000%20Mini%20Toggle%20Series.pdf)); la figura DPDT de la página 2 nombra el 7201SYZQE. El código se lee así: 7201 = DP On-None-On, S = palanca de 0,420 in, Y = casquillo de 0,350 in con chaveta y rosca 1/4-40, Z = seis terminales de soldar, Q = material de contacto, E = sellado de epoxy. Los comunes son los terminales 2 y 5. ON es la palanca lejos de la chaveta (posición 3 de la hoja): cierra 2-1 y 5-4. OFF es la palanca hacia la chaveta (posición 1): cierra 2-3 y 5-6. El cable va terminal a taladro, uno a uno: pad 1 `VLOG` al terminal 1, pad 2 `EN2_CE` al terminal 2, pad 3 `GND` al terminal 3, pad 4 `BAT_PROT` al terminal 4, pad 5 `TPS_EN` al terminal 5 y pad 6 `VLOG` al terminal 6. Así, ON une `EN2_CE` con `VLOG` y `TPS_EN` con `BAT_PROT`; OFF une `EN2_CE` con `GND` y `TPS_EN` con `VLOG`. Los seis taladros no tienen código de compra; el código es el de la pieza de la caja.

Con OFF y VBUS válido: `EN1=alto`, `EN2=bajo`, `CE=bajo` permiten carga y salida desde USB, con límite USB500 solo si la fuente lo admite. Con ON y VBUS válido: `EN1=EN2=alto` ponen el BQ24074 en *standby/USB suspend*: `Q1` interno (IN→OUT) abierto, `Q2` (BAT→OUT) cerrado y carga detenida. `CE=alto` añade inhibición de carga, pero no basta por sí solo para evitar que USB alimente `OUT`. Los niveles de `EN1`, `EN2` y `CE` deben provenir del interruptor y VBUS, seguir definidos sin batería y no depender de firmware. `ILIM`, `ISET` e `ITERM` se calculan para la fuente, la LiPo y la carga prevista de ≈300 mA. `TMR` lleva 46,4 kΩ al 1 % a masa. `TS` va al NTC.

La lógica derivada de VBUS debe respetar en cada pin `EN1`, `EN2` y `CE`: bajo **0–0,4 V**, alto **1,4–6 V**, máximo absoluto **−0,3 a 7 V**, incluso durante transitorios. El esquema debe incluir la limitación/protección necesaria y margen respecto a 6 V en operación; los 7 V no son una consigna. La tolerancia de `IN` a una tensión mayor no se extiende a estos pines. Véase [alimentación y USB](alimentacion-usb.md).

La habilitación del TPS63070 debe obedecer por hardware a `(OFF y VBUS válido) o (ON y batería válida)`. Así OFF+USB admite programación sin batería, mientras ON+USB sin batería no arranca. El esquema debe definir la detección de batería válida y comprobar las transiciones de fuente al mover ON→OFF. [Hoja de datos BQ24074 de TI](https://www.ti.com/lit/ds/symlink/bq24074.pdf), tabla 7-2 y apartado 9.3.2.

| Interruptor | USB | Modo BQ24074 | Fuente de 3V3 | Carga | USB datos/programación | Uso con persona |
|---|---:|---|---|---|---|---|
| OFF | no | entrada inválida | ninguna | no | no | no hay adquisición |
| OFF | sí | USB500, si fuente válida | VBUS vía BQ24074 | sí | sí | no conectar a una persona |
| ON | no | entrada inválida | LiPo | no | no | adquisición con batería |
| ON | sí | standby, `EN1=EN2=alto` | LiPo | no | sí | solo con aislador USB externo |

Con OFF y USB, el ESP puede arrancar para programarse; al retirar USB queda apagado. Con ON y USB, D+/D− continúan funcionando y `OUT` se alimenta de la batería, aunque VBUS permanece en `IN` del cargador. Para medir con USB conectado se requiere un aislador externo alimentado desde el ordenador; la masa del conector de placa no se corta, pues el retorno de datos forma parte de ese aislamiento externo. Un cable USB normal no debe usarse sobre una persona.

## 3. Conectores hacia sensores y regla de uso

Los conectores `J_ECG`, `J_PPG`, `J_TEMP`, `J_GSR`, `J_RESP_T` y `J_RESP_A` van a sus circuitos sin relés, conmutadores ni contactos de corte. OFF deshabilita el sistema salvo cuando USB lo alimenta para carga y mantenimiento. Por tanto, OFF **no** separa eléctricamente los módulos ni los electrodos del USB; durante la carga o programación con USB directo se desconecta a la persona y sus sensores.

La placa no incluye aislamiento galvánico interno ni detecta si hay aislador externo. Con USB durante una medición, el aislamiento depende del dispositivo externo y del procedimiento de uso. `usb_present` es información de estado, no una prueba de aislamiento.

## 4. Módulos y adquisición

| Conector / señal | Interfaz | Requisitos eléctricos |
|---|---|---|
| AD8232 externo | 3V3, GND, OUTPUT, LO+, LO−, SDN | Verificar breakout a 3,3 V. ADS ECG: referencia interna 2,048 V, PGA bypass, ganancia 1, 600 SPS. Divisor: 33,2 kΩ desde OUTPUT y 47,5 kΩ a masa, al 1 %. A 3,30 V de salida plena el ADS ve 1,94 V; a 3,40 V ve 2,00 V, por debajo de 2,048 V. No usar 20,0/40,2 kΩ. La medida de la excursión real comprueba que el módulo no recorta antes del divisor. Si OUTPUT ya sale recortada, el divisor no lo corrige. |
| MAX30102/GY-30102 | 3V3, GND, SCL, SDA, INT | Verificar reguladores, niveles, *pull-ups*, LED y consumo del módulo real. PPG inicialmente 200 pares/s. |
| CJMCU-30205 | 3V0_TEMP, GND, SDA, SCL (conector de 4 pines) | VCC del módulo va directo al chip: no lleva regulador. A0, A1 y A2 del módulo van a GND en el propio módulo (estaño o hilo corto), no por el cable, y fijan 0x48. OS del módulo queda sin conectar (el módulo lleva su pull-up de 10 kΩ). Las pull-up del módulo van a su VCC. |
| GSR | Dos electrodos | `0V5_EXC → 100 kΩ → sensor → retorno`; seguidor MCP6004 y ADS lento. Corriente de cortocircuito ≈5 µA. |
| Bandas tórax/abdomen | Dos hilos por banda | Mismo frontal que GSR, con resistencia fija de 100 kΩ revisable tras medir bandas reales. |

Los IDAC de los ADS permanecen apagados y no se conectan a rutas corporales. GSR y bandas se muestrean inicialmente a 20 SPS por canal; se publican estados OPEN, SHORT, OUT_OF_RANGE y UNCALIBRATED. Las bandas producen resistencia y curva respiratoria, no volumen pulmonar.

I²C de ADC (GPIO4/5) opera a 400 kHz con ADS `0x40` y `0x41`; DRDY entra por GPIO6/7. I²C de módulos (GPIO8/9) empieza a 100 kHz; INT PPG usa GPIO10. `BAT_SENSE` (GPIO1) usa divisor 1 MΩ/330 kΩ conmutado, filtro y calibración. GPIO0 queda reservado para BOOT, con 10 kΩ a `3V3_SYS`; el pulsador de BOOT lo lleva a masa. D−/D+ son GPIO19/20, cada una con sus 22 Ω en serie.

## 5. Placa

Cuatro capas. La placa mide **84,50 × 53,11 mm**; la anchura deja sitio para serigrafiar J3 fuera del conector. El USB-C está en el borde inferior y su boca sobresale del contorno. El ESP32-S3-MINI-1U no lleva antena de circuito impreso: lleva conector U.FL. Ese extremo del módulo queda en el borde superior, lo más salido posible, para que la antena externa quede fuera del cobre. En todas las capas, bajo ese extremo y un poco más allá del borde del módulo hacia fuera, no hay cobre, pistas, vías ni plano. El USB y el buck no se colocan bajo esa zona.

Hay dos planos de masa. La masa digital reúne el ESP32, el USB, el BQ24074 y el TPS63070. La masa analógica reúne los ADS122C04, el MCP6004, el divisor de ECG, el GSR y las bandas. Se unen en un solo sitio, corto y ancho, junto a los ADS y al puente de 0 Ω entre `3V3_SYS` y `3V3_A`, de modo que alimentación y retorno coinciden en el mismo punto. No hay varias uniones repartidas ni una pista fina cruzando la placa. Las señales analógicas no cruzan la masa digital. In1 es masa, partida en esas dos zonas. F.Cu lleva el mismo reparto, cosido con vías a su zona. In2 es `3V3_SYS` y no lleva señales de datos. B.Cu lleva las señales.

Los dos nodos del inductor del TPS63070 quedan en F.Cu, sin vía, a 0,40 mm en todo el tramo.

## 6. Verificación obligatoria

1. Fotografiar y medir cada breakout: pinout, reguladores, *pull-ups*, consumo y dimensiones.
2. Ensayar los cuatro estados USB/interruptor, incluso sin batería: con ON y USB, `OUT` sigue a BAT y la corriente de carga es nula; sin batería, D+/D− y VBUS no pueden elevar 3V3. Medir con osciloscopio `EN1`, `EN2` y `CE` durante los estados y transiciones, y comprobar sus límites de tensión.
3. Medir 3V3 en el ESP y 3V0 en el VCC del CJMCU-30205, rizado, picos BLE/PPG y carga del BQ24074. En el módulo de pulso, con el LED encendido y el cable puesto, VIN no debe bajar de 3,1 V.
4. Verificar que ningún conector de sensor queda alimentado por error con el sistema realmente apagado y sin USB; con OFF+USB, documentar expresamente que puede haber tensión en los conectores.
5. Demostrar limitación GSR ante corto y ausencia de bypass de los 100 kΩ.
6. Medir excursión AD8232, saturación ADS, ruido 50/60 Hz, respuesta de bandas y buses con cables reales.
7. Validar aislamiento externo y datos USB durante adquisición antes de permitir ese modo de uso.

El proyecto KiCad 9.0.9 incluye esquemático, PCB, BOM, Gerbers, taladros y `position.csv`; ERC, DRC y paridad dan cero. Antes de fabricar una tirada se requieren huellas verificadas contra las piezas compradas, revisión de las rutas al cuerpo y del uso previsto del aislador externo, y ensayos de la primera placa.

## 7. Contrato de la implementación

- J3, módulo AD8232 externo: pin 1 AGND/GND, 2 3V3_A/3.3V, 3 ECG_OUT/OUTPUT, 4 LO_N/LO−, 5 LO_P/LO+, 6 3V3_A/SDN. SDN queda siempre habilitado. Es el orden del módulo rojo para un cable plano.
- J5, CJMCU-30205: pin 1 3V0_TEMP, 2 GND, 3 SDA, 4 SCL. J9, medidor de batería: JST PH B2B-PH-K-S(LF)(SN), pin 1 BAT+ conmutado, pin 2 GND. Un BSS84LT1G de lado alto y un BSS138LT1G lo activan solo cuando existe 3V3_SYS; 1 MΩ une puerta y fuente del BSS84. J9 queda reservado al medidor de batería.
- R39, YAGEO RC0603FR-0710KL de 10 kΩ al 1 %, está en serie entre TPS_EN y el pin EN del TPS63070, pegado al regulador. R12 de 100 kΩ a masa queda del lado del interruptor. PS/SYNC sigue a masa. R3 sigue en 0 Ω.
- L1 es Coilcraft **XAL4020-152MEC**, 1,5 µH y huella XAL4020 sin cambios; «C» identifica el embalaje de bobina de 7 pulgadas.
- La serigrafía de J3 está fuera del conector, en una columna alineada con los seis pines. El logo PINA figura en la esquina superior derecha y una copia pequeña acompaña al título «PINABio \"Paca\" v.2.0.» en dos líneas en la zona central derecha. J2 se rotula BATT; las cinco etiquetas de J4 (VIN, GND, SCL, SDA, INT) comparten la misma alineación izquierda. Todos los nombres y etiquetas de pin usan texto de al menos 1,0 mm de altura y 0,15 mm de trazo.

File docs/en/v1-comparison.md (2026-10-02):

# PinaBio V1 versus V2 — revision `CMP-0.4`

V1 has published PCB, firmware and application material. V2 now has a KiCad 9.0.9 prototype schematic and PCB with zero ERC, DRC and schematic/PCB parity issues, but no assembled and tested board, V2 firmware or V2 application. V2 proposes a dedicated 600 SPS ADS122C04 ECG path, a separate slow ADS path, PPG interrupt timing and a protected LiPo/BQ24074/TPS63070 power tree. Sensor connectors have no automatic cutoff.

The revised V2 uses a 3.3 V rail plus a 3.0 V LDO for the temperature module, rather than a 2.9 V analogue rail, charges/programs with switch OFF, and permits USB data with switch ON only through a host-powered external isolator during person-connected use. These are unvalidated design targets, not measured safety or performance claims. V2 is intentionally incompatible with V1.1 software and has no compatibility adapter.

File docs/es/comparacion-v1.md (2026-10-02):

# PinaBio V1 frente a V2 — revisión `CMP-0.4`

[Portada](../../README.md) · [Especificación V2](especificacion.md)

V1 cuenta con placa, firmware y aplicación publicados. V2 ya tiene esquemático y PCB de prototipo en KiCad 9.0.9 con ERC/DRC/paridad cero, pero todavía no hay una placa montada, firmware ni aplicación V2 verificados. Las mejoras son objetivos de diseño, no prestaciones demostradas.

| Aspecto | V1 | V2 revisada | Condición |
|---|---|---|---|
| ECG | ADS1115 compartido | ADS122C04 dedicado, 600 SPS y DRDY | Verificar ruido, divisor y 50/60 Hz. |
| GSR / respiración | Excitación ≈0,5 V, tres señales lentas | ADS lento separado, MCP6004 y 100 kΩ físicos en serie | Medir sensibilidad de bandas y corriente de fallo. |
| PPG / temperatura | Módulos existentes | Módulos externos con INT PPG y conectores directos | Verificar cada breakout y niveles a 3,3 V / 3,0 V. |
| Alimentación | Regulación distribuida de V1 | LiPo + BQ24074 + TPS63070 a 3,3 V y TLV75530PDBVR a 3,0 V solo para temperatura | Medir picos y carga; no hay 2,9 V. |
| USB | Regla de no usar USB sobre la piel | Carga/programación con OFF; datos con ON y aislador externo | Aislador medido desde el lado host; cable normal no apto sobre persona. |
| Conexiones al cuerpo | Conectores directos | Conectores directos; el aislamiento con USB durante adquisición es externo | No hay desconexión automática de sensores al conectar USB. |
| Software | Firmware/app V1.1 | PROTO-0.4 nuevo, no implementado | Sin compatibilidad ni adaptador V1.1. |

V2 aumenta control de potencia, temporización y separación de adquisición, pero todavía retrocede en madurez hasta montar y ensayar el prototipo y completar firmware y aplicación.

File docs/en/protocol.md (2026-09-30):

# PinaBio Paca — firmware, BLE and data contract `PROTO-0.5`

This is a proposed protocol, not implemented firmware. Multibyte fields are little-endian; raw data, calibration and loss markers are retained and the board makes no diagnosis.

States are `BOOT`, `IDLE_USB`, `IDLE_BATTERY`, `ACQUIRING`, `LOW_BATTERY`, `SENSOR_FAULT` and `INTERNAL_FAULT`. `LEADS_OFF` remains an ECG flag. VBUS is not an automatic lockout: `ACQUIRING` may be entered with ON, battery and a correctly fitted external isolator. Firmware reports `physical_vbus` and `isolation_unverified`; it cannot certify the cable. START requires ON, power-good and sensor self-test. There are no sensor cutoff relays or contact-feedback signals. With OFF+USB, remove sensors from the person before charging or programming.

ECG uses ADS `0x40` at 600 SPS; GSR, thorax and abdomen use ADS `0x41` in single-shot mode at an initial 20 SPS per channel. PPG starts at 200 RED/IR pairs per second and temperature/battery at 1 Hz. BLE service and frame compatibility remain as `PROTO-0.3`: service UUID `b88b0000-1a8c-4a2b-ae02-50494e414249`, Control/Data/Status/Metadata/ControlResult characteristics, minimum MTU 128, 22-byte header and CRC-16/CCITT-FALSE.

STATUS includes state, reason, `physical_vbus`, `isolation_unverified`, ADC overrun, BLE loss and PPG overflow. START may fail with `LOW_BATTERY`, `SENSOR_FAULT`, `INTERNAL_FAULT` or `MTU_TOO_SMALL`; `CONTACT_OPEN` and `VBUS_LOCKOUT` are removed. Test data loss, MTU, ECG/PPG timing and USB acquisition with a measured external isolator before implementation release.

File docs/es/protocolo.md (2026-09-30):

# PinaBio Paca — contrato de firmware, BLE y datos `PROTO-0.5`

[Portada](../../README.md) · [Especificación](especificacion.md)

Propuesta de protocolo, no firmware implementado. Campos multibyte en *little-endian*. El protocolo conserva datos crudos, calibración y pérdidas; no diagnostica ni calcula HRV en la placa.

## Estados e inicio de adquisición

Estados: `BOOT`, `IDLE_USB`, `IDLE_BATTERY`, `ACQUIRING`, `LOW_BATTERY`, `SENSOR_FAULT` e `INTERNAL_FAULT`. `LEADS_OFF` es una bandera de ECG. VBUS no es por sí mismo un bloqueo: con ON, batería presente y aislador USB externo puede existir `ACQUIRING`. El firmware no puede detectar de forma fiable el aislador y debe informar `usb_present` y `isolation_unverified` en STATUS; la aplicación muestra una advertencia inequívoca y el usuario confirma el procedimiento seguro antes de START.

START exige ON físico, alimentación válida y autocomprobación de buses/ADC. No hay relés de corte ni realimentación de contactos de sensores. OFF quita la alimentación desde batería, pero OFF+USB sigue encendiendo el sistema para carga y mantenimiento; los sensores deben estar retirados de la persona en ese estado. Wi‑Fi queda desactivado desde el arranque.

## Muestreo

- ECG: ADS `0x40`, 600 SPS continuo, referencia interna 2,048 V, ganancia 1, PGA bypass; GPIO6 marca DRDY.
- GSR, tórax y abdomen: ADS `0x41`, MUX→START→DRDY→READ, 20 SPS efectivos por canal inicial; GPIO7 marca DRDY.
- PPG: MAX30102, RED+IR, 200 pares/s iniciales; GPIO10 dispara vaciado FIFO. El tiempo individual se reconstruye y se marca `TIMING_ESTIMATED` hasta validar deriva.
- Temperatura y batería: 1 Hz inicial. GSR y bandas conservan ADS crudo más magnitud y estado de calidad.

## BLE y trama

Servicio provisional `b88b0000-1a8c-4a2b-ae02-50494e414249`; características `0001` Control, `0002` Data, `0003` Status, `0004` Metadata y `0005` ControlResult. MTU objetivo 247 y mínimo 128 para START.

La trama mantiene cabecera de 22 bytes y CRC16/CCITT-FALSE final: `magic u16=0x5042`, `major u8=1`, `type u8` (ECG/PPG/SLOW/STATUS), `seq u16`, `flags u16`, `t0_us u64`, `period_ns u32`, `count u16`, payload y CRC16. ECG es s24 LE; PPG son RED u24 + IR u24; SLOW contiene `channel u8`, `quality u8`, `dt_us u16`, `value_s32` y `raw_s32`. Los canales SLOW son GSR, THORAX, ABDOMEN, TEMP y BATTERY.

`STATUS` incluye estado, motivo, `physical_vbus`, `isolation_unverified`, `adc_overrun`, `ble_drop` y `ppg_overflow`. Los motivos de START incluyen `LOW_BATTERY`, `SENSOR_FAULT`, `INTERNAL_FAULT` y `MTU_TOO_SMALL`; no existen `CONTACT_OPEN` ni `VBUS_LOCKOUT`. `LEADS_OFF` sigue siendo una bandera del AD8232, no un estado de relé.

## Control, pérdida y pruebas

`START` recibe máscara de canales y devuelve sesión y tasas concedidas; `STOP`, `GET_STATUS` y `SET_PPG` conservan su semántica. No se habilitan AUX ni IDAC. Si los anillos se llenan se descartan muestras antiguas completas y la siguiente trama lleva `GAP_BEFORE`; nunca se repiten o inventan muestras.

Se deben probar diez minutos de ECG/PPG, pérdidas BLE y MTU insuficiente, batería baja, saturación, FIFO PPG, CRC y los cuatro estados USB/interruptor. La prueba de adquisición con USB exige aislador externo medido: no puede aprobarse solo con una bandera de software.

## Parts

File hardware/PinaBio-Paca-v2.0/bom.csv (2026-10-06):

Reference | Value | Footprint | Manufacturer | MPN | Voltage | Dielectric | Datasheet | Qty
J1 | USB-C | Connector_USB:USB_C_Receptacle_HCTL_HC-TYPE-C-16P-01A | HCTL | HC-TYPE-C-16P-01A |  |  | ~ | 1
R1 R2 | 5.1k | Resistor_SMD:R_0603_1608Metric | YAGEO | RC0603FR-075K1L |  |  | ~ | 2
U1 | USBLC6-2SC6 | Package_TO_SOT_SMD:SOT-23-6 | STMicroelectronics | USBLC6-2SC6 |  |  | https://www.st.com/resource/en/datasheet/usblc6-2.pdf | 1
R35 R36 | 22 | Resistor_SMD:R_0603_1608Metric | YAGEO | RC0603FR-0722RL |  |  | ~ | 2
R3 R15 | 0 | Resistor_SMD:R_0603_1608Metric | YAGEO | RC0603JR-070RL |  |  | ~ | 2
R4 | 10.0k | Resistor_SMD:R_0603_1608Metric | YAGEO | RC0603FR-0710KL |  |  | ~ | 1
R5 | 15.0k | Resistor_SMD:R_0603_1608Metric | YAGEO | RC0603FR-0715KL |  |  | ~ | 1
D1 | BZX84-C3V6 | Package_TO_SOT_SMD:SOT-23 | Nexperia | BZX84-C3V6,215 |  |  | https://assets.nexperia.com/documents/data-sheet/BZX84_SERIES.pdf | 1
U2 | BQ24074 | Package_DFN_QFN:VQFN-16-1EP_3x3mm_P0.5mm_EP1.6x1.6mm | Texas Instruments | BQ24074RGTR |  |  | https://www.ti.com/lit/ds/symlink/bq24074.pdf | 1
R6 R7 | 2.94k 1% | Resistor_SMD:R_0603_1608Metric | YAGEO | RC0603FR-072K94L |  |  | https://www.ti.com/lit/ds/symlink/bq24074.pdf | 2
R37 | 46.4k 1% | Resistor_SMD:R_0603_1608Metric | YAGEO | RC0603FR-0746K4L |  |  | https://www.ti.com/lit/ds/symlink/bq24074.pdf | 1
R8 | 2.2k | Resistor_SMD:R_0603_1608Metric | YAGEO | RC0603FR-072K2L |  |  | ~ | 1
R9 R10 R11 R12 R19 R20 R21 R30 R31 R32 | 100k | Resistor_SMD:R_0603_1608Metric | YAGEO | RC0603FR-07100KL |  |  | ~ | 10
C1 | 4.7uF | Capacitor_SMD:C_0603_1608Metric | Samsung Electro-Mechanics | CL10A475KO8NNNC | 16V | X5R | ~ | 1
C2 C3 C4 C5 C6 C10 C16 | 10uF | Capacitor_SMD:C_0805_2012Metric | Samsung Electro-Mechanics | CL21A106KOQNNNE | 16V | X5R | ~ | 7
SW1 | DPDT caja | PinaBio:SW_ext_6pad |  |  |  |  | https://media.digikey.com/pdf/Data%20Sheets/C&K/7000%20Mini%20Toggle%20Series.pdf | 1
R39 R29 | 10k 1% | Resistor_SMD:R_0603_1608Metric | YAGEO | RC0603FR-0710KL |  |  | https://www.ti.com/lit/ds/symlink/tps63070.pdf | 2
U3 | TPS63070 | PinaBio:TPS63070RNM | Texas Instruments | TPS63070RNMR |  |  | https://www.ti.com/lit/ds/symlink/tps63070.pdf | 1
L1 | 1.5uH | Inductor_SMD:L_Coilcraft_XAL4020-XXX | Coilcraft | XAL4020-152MEC |  |  | https://www.coilcraft.com/getmedia/6adcb47d-8b55-416c-976e-1e22e0d2848c/xal4000.pdf | 1
C7 C8 C9 | 22uF | Capacitor_SMD:C_0805_2012Metric | Samsung Electro-Mechanics | CL21A226MAYNNNE | 25V | X5R | ~ | 3
C11 C14 C17 C18 C19 C20 C21 C22 | 100nF | Capacitor_SMD:C_0603_1608Metric | Samsung Electro-Mechanics | CL10B104KB8NNNC | 50V | X7R | ~ | 8
R13 | 49.9k 0.1% | Resistor_SMD:R_0603_1608Metric | YAGEO | RT0603BRD0749K9L |  |  | https://www.ti.com/lit/ds/symlink/tps63070.pdf | 1
R14 | 16.0k 0.1% | Resistor_SMD:R_0603_1608Metric | YAGEO | RT0603BRD0716KL |  |  | https://www.ti.com/lit/ds/symlink/tps63070.pdf | 1
U4 | TLV75530PDBVR | Package_TO_SOT_SMD:SOT-23-5 | Texas Instruments | TLV75530PDBVR |  |  | https://www.ti.com/lit/ds/symlink/tlv755p.pdf | 1
C12 C13 | 2.2uF | Capacitor_SMD:C_0805_2012Metric | Samsung Electro-Mechanics | CL21B225KAFNNNE | 25V | X7R | ~ | 2
Q1 Q4 | BSS84 | Package_TO_SOT_SMD:SOT-23 | onsemi | BSS84LT1G |  |  | https://www.onsemi.com/pdf/datasheet/bss84-d.pdf | 2
Q2 Q3 Q5 | BSS138 | Package_TO_SOT_SMD:SOT-23 | onsemi | BSS138LT1G |  |  | https://www.onsemi.com/pdf/datasheet/bss138-d.pdf | 3
R16 R17 R40 | 1M | Resistor_SMD:R_0603_1608Metric | YAGEO | RC0603FR-071ML |  |  | ~ | 3
R18 | 330k | Resistor_SMD:R_0603_1608Metric | YAGEO | RC0603FR-07330KL |  |  | ~ | 1
J2 | J_BATT | Connector_JST:JST_PH_B3B-PH-K_1x03_P2.00mm_Vertical | JST | B3B-PH-K-S(LF)(SN) |  |  | ~ | 1
J9 | J_BATT_METER | Connector_JST:JST_PH_B2B-PH-K_1x02_P2.00mm_Vertical | JST | B2B-PH-K-S(LF)(SN) |  |  | ~ | 1
U5 | ESP32-S3-MINI-1U-N8 | RF_Module:ESP32-S2-MINI-1U | Espressif | ESP32-S3-MINI-1U-N8 |  |  | https://www.espressif.com/sites/default/files/documentation/esp32-s3-mini-1_mini-1u_datasheet_en.pdf | 1
R22 R38 R25 R26 R27 | 10k | Resistor_SMD:R_0603_1608Metric | YAGEO | RC0603FR-0710KL |  |  | https://www.espressif.com/sites/default/files/documentation/esp32-s3-mini-1_mini-1u_datasheet_en.pdf | 5
C15 | 1uF | Capacitor_SMD:C_0603_1608Metric | Samsung Electro-Mechanics | CL10A105KB8NNNC | 50V | X5R | ~ | 1
SW2 | BOOT | Button_Switch_SMD:SW_SPST_B3U-1000P | Omron | B3U-1000P |  |  | ~ | 1
R23 R24 | 4.7k | Resistor_SMD:R_0603_1608Metric | YAGEO | RC0603FR-074K7L |  |  | ~ | 2
U6 U7 | ADS122C04 | Package_SO:TSSOP-16_4.4x5mm_P0.65mm | Texas Instruments | ADS122C04IPWR |  |  | https://www.ti.com/lit/ds/symlink/ads122c04.pdf | 2
U8 | MCP6004 | Package_SO:SOIC-14_3.9x8.7mm_P1.27mm | Microchip | MCP6004-I/SL |  |  | https://ww1.microchip.com/downloads/en/DeviceDoc/MCP6001-1R-1U-2-4-1-MHz-Low-Power-Op-Amp-DS20001733L.pdf | 1
R28 | 56k 1% | Resistor_SMD:R_0603_1608Metric | YAGEO | RC0603FR-0756KL |  |  | ~ | 1
R33 | 33.2k 1% | Resistor_SMD:R_0603_1608Metric | YAGEO | RC0603FR-0733K2L |  |  | ~ | 1
R34 | 47.5k 1% | Resistor_SMD:R_0603_1608Metric | YAGEO | RC0603FR-0747K5L |  |  | ~ | 1
J3 | J_ECG | Connector_JST:JST_PH_B6B-PH-K_1x06_P2.00mm_Vertical | JST | B6B-PH-K-S(LF)(SN) |  |  | ~ | 1
J4 | J_PPG | Connector_JST:JST_PH_B5B-PH-K_1x05_P2.00mm_Vertical | JST | B5B-PH-K-S(LF)(SN) |  |  | ~ | 1
J5 | J_TEMP | Connector_JST:JST_PH_B4B-PH-K_1x04_P2.00mm_Vertical | JST | B4B-PH-K-S(LF)(SN) |  |  | ~ | 1
J6 | J_GSR | Connector_JST:JST_PH_B2B-PH-K_1x02_P2.00mm_Vertical | JST | B2B-PH-K-S(LF)(SN) |  |  | ~ | 1
J7 | J_RESP_T | Connector_JST:JST_PH_B2B-PH-K_1x02_P2.00mm_Vertical | JST | B2B-PH-K-S(LF)(SN) |  |  | ~ | 1
J8 | J_RESP_A | Connector_JST:JST_PH_B2B-PH-K_1x02_P2.00mm_Vertical | JST | B2B-PH-K-S(LF)(SN) |  |  | ~ | 1

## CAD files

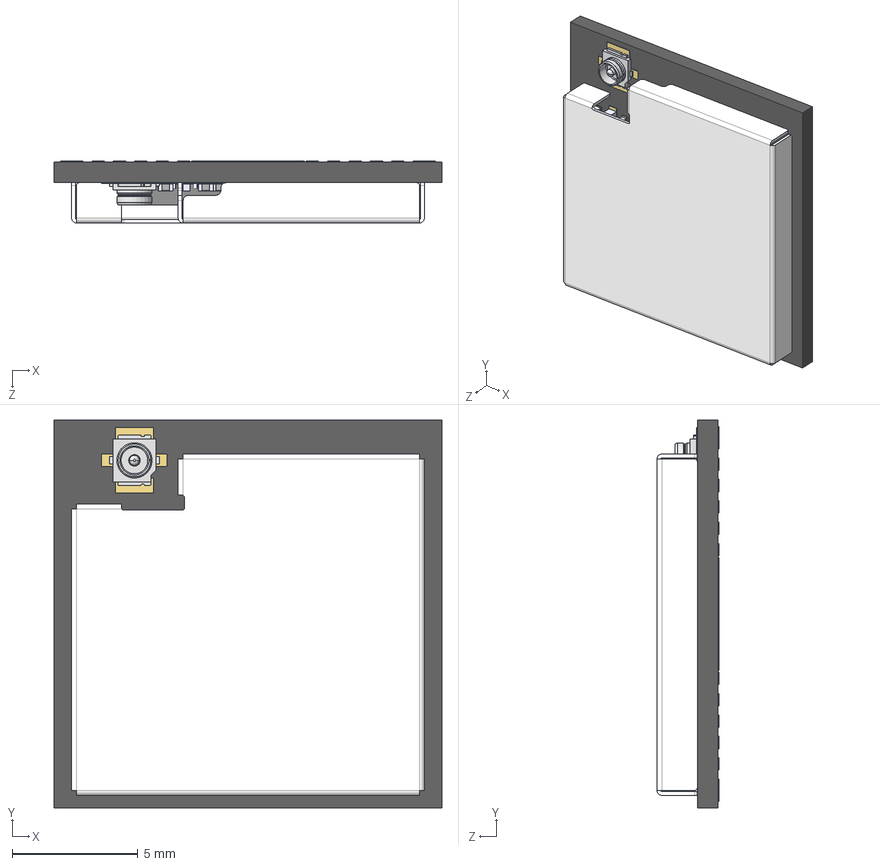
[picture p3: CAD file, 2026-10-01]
hardware/PinaBio-Paca-v2.0/3dmodels/ESP32-S3-MINI-1U.STEP
15.4 x 15.4 x 2.46 mm
uid__2482
R0201_20210301.xtd x 3
L0201_20210301.xtd x 2
C0201_20210301.xtd x 13
C0402_20210301.xtd
DFN1006.xtd
XTAL3225_20210301.xtd
ipx3.xtd
ESP32-S3_20210301.xtd
Imported
Shield Box_ESP32-S3-MINI-1U_20200714

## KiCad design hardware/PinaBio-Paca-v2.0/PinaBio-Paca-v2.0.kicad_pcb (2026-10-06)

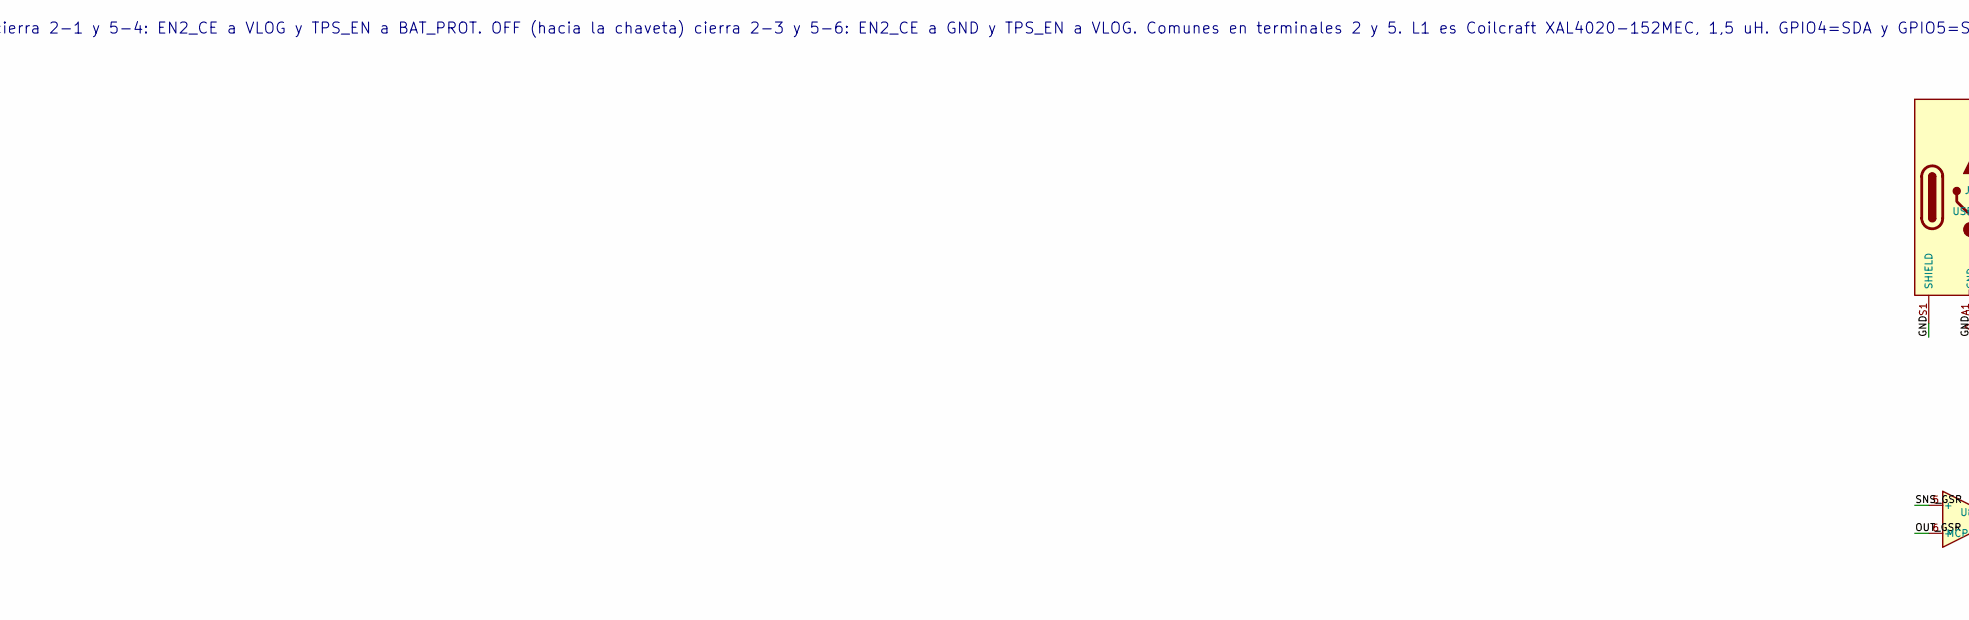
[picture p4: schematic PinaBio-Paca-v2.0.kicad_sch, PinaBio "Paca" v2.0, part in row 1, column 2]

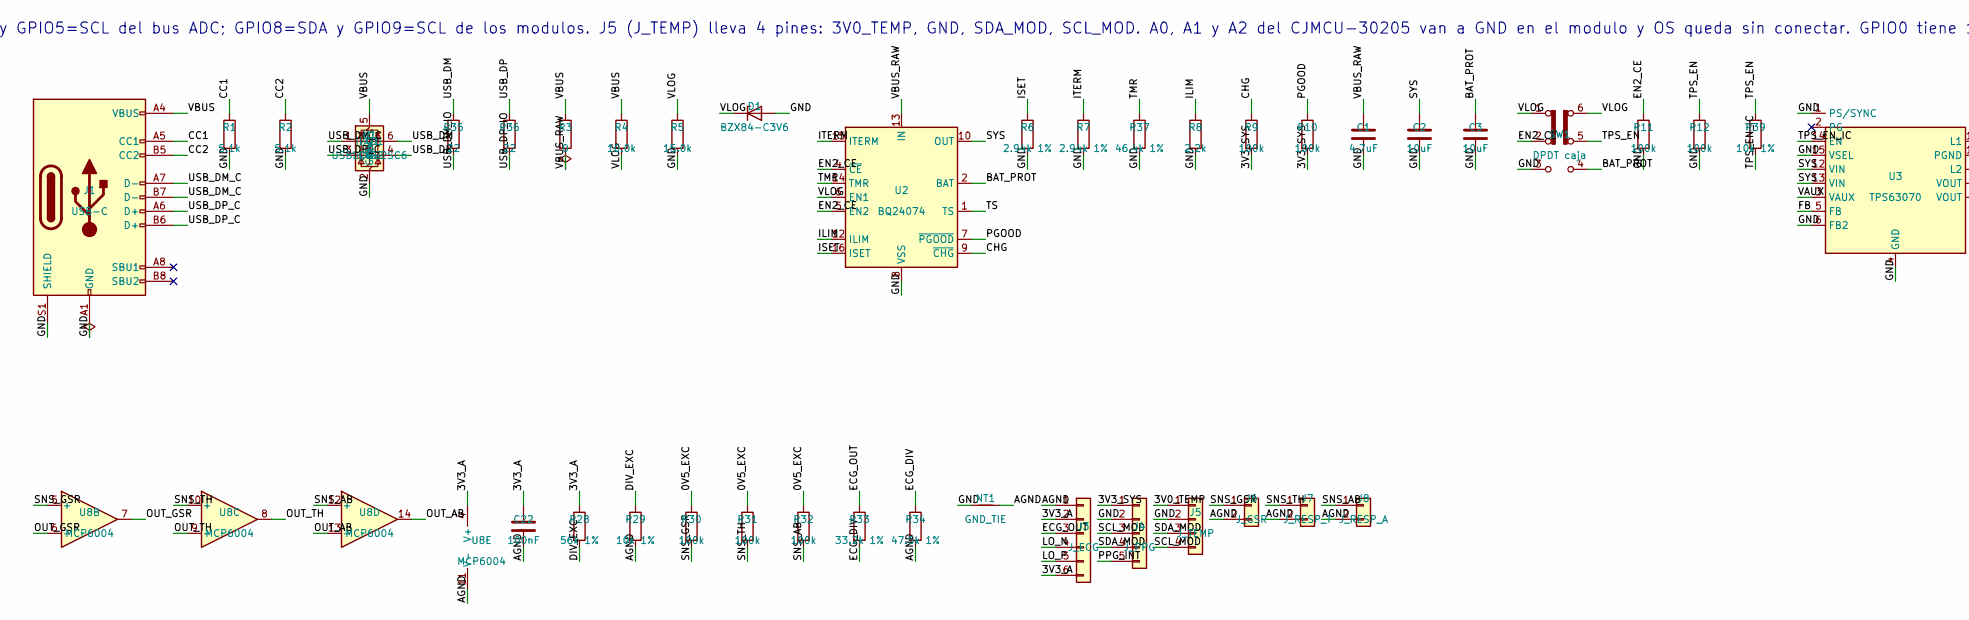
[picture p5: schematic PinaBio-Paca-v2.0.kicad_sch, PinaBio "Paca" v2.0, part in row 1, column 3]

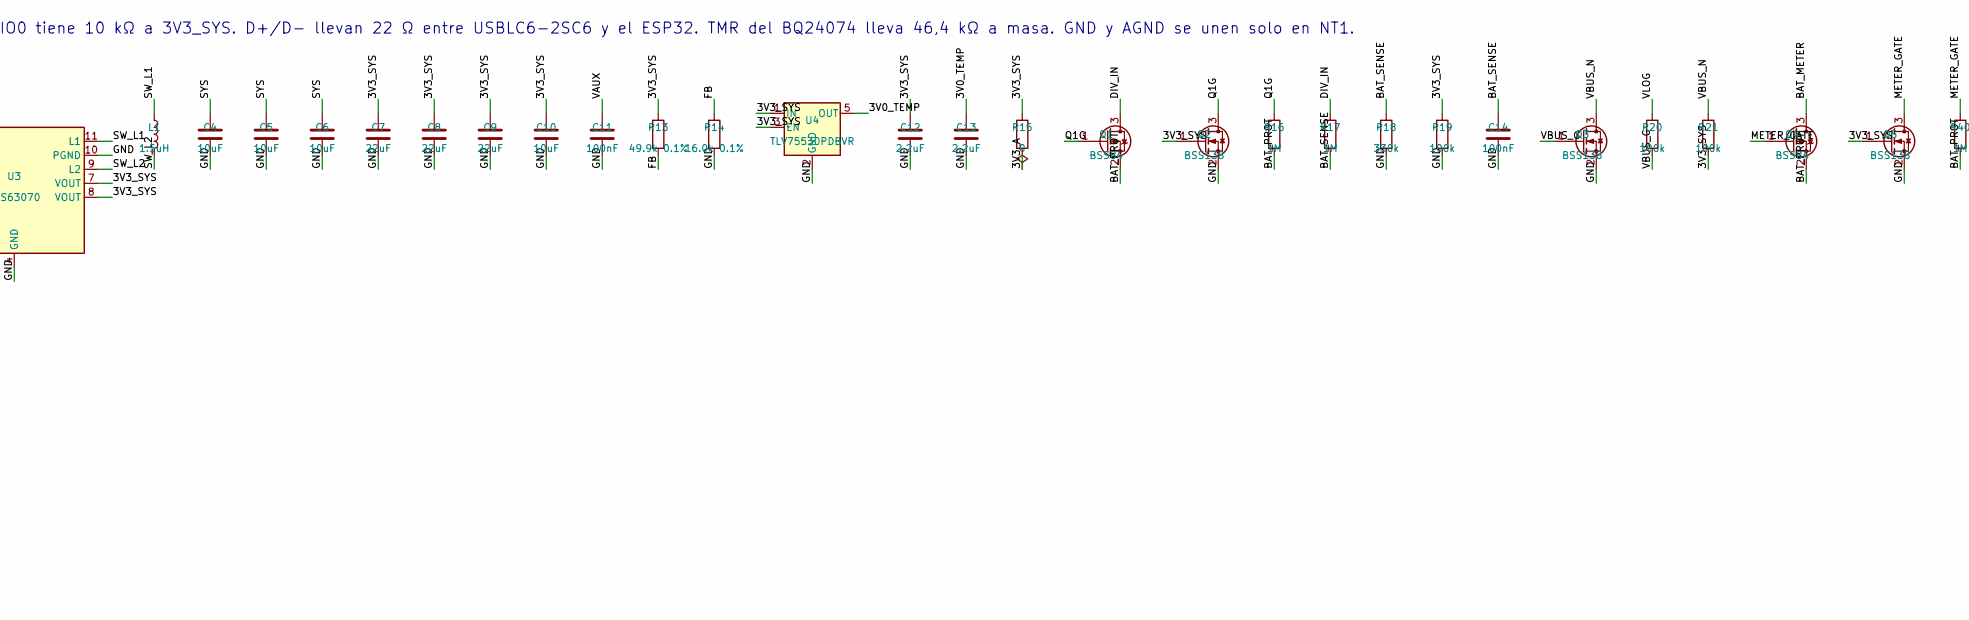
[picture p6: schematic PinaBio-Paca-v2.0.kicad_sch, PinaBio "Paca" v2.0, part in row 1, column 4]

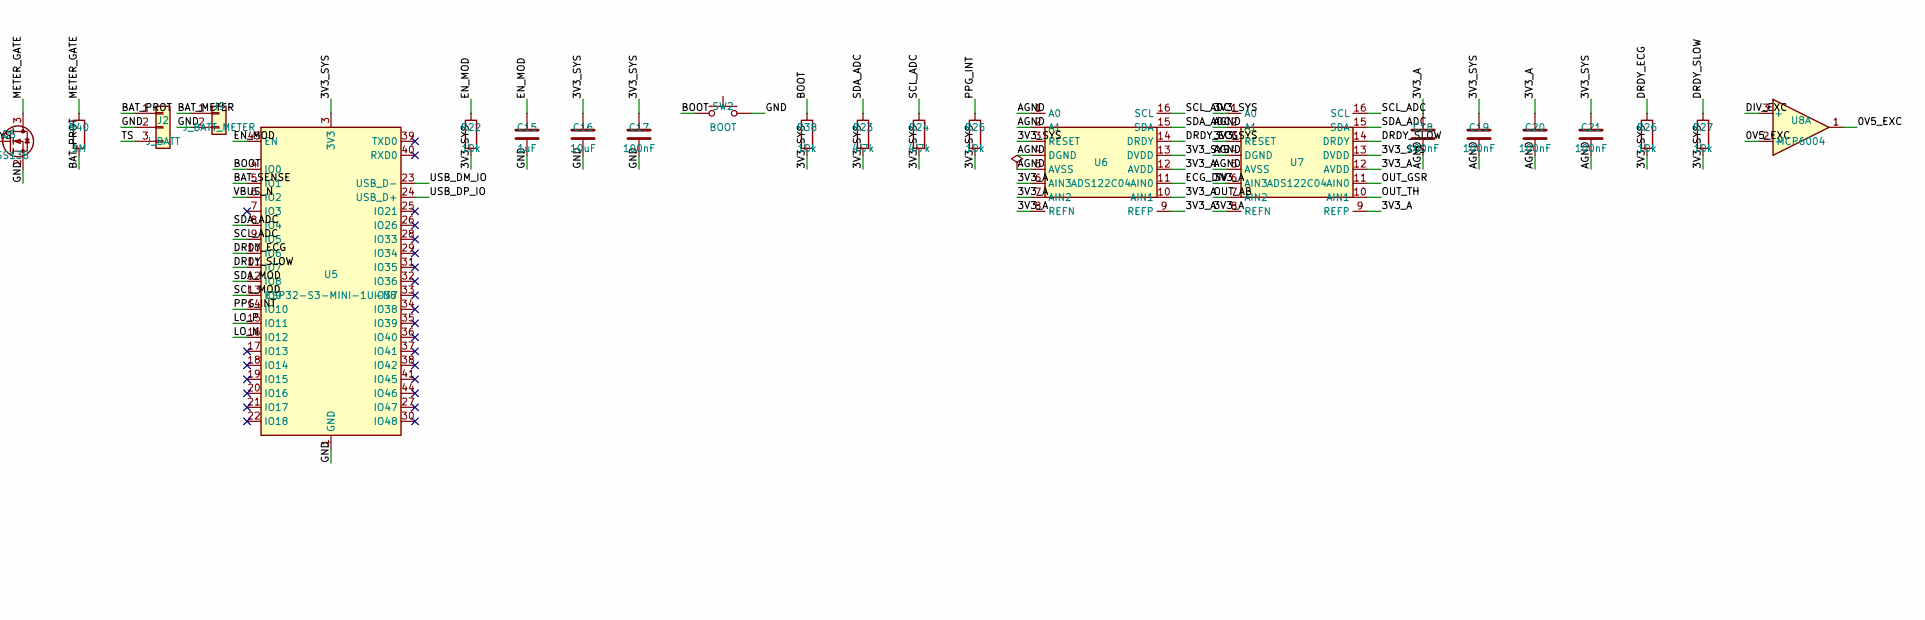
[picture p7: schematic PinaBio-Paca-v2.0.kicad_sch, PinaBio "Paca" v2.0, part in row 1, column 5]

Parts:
C1: 4.7uF; C_0603_1608Metric; Voltage 16V; MPN CL10A475KO8NNNC
C2, C3, C4, C5, C6, C10, C16: 10uF; C_0805_2012Metric; Voltage 16V; MPN CL21A106KOQNNNE
C7, C8, C9: 22uF; C_0805_2012Metric; Voltage 25V; MPN CL21A226MAYNNNE
C11, C14, C17, C18, C19, C20, C21, C22: 100nF; C_0603_1608Metric; Voltage 50V; MPN CL10B104KB8NNNC
C12, C13: 2.2uF; C_0805_2012Metric; Voltage 25V; MPN CL21B225KAFNNNE
C15: 1uF; C_0603_1608Metric; Voltage 50V; MPN CL10A105KB8NNNC
D1: BZX84-C3V6; SOT-23; MPN BZX84-C3V6,215
J1: USB-C; USB_C_Receptacle_HCTL_HC-TYPE-C-16P-01A; MPN HC-TYPE-C-16P-01A
J2: J_BATT; JST_PH_B3B-PH-K_1x03_P2.00mm_Vertical; MPN B3B-PH-K-S(LF)(SN)
J3: J_ECG; JST_PH_B6B-PH-K_1x06_P2.00mm_Vertical; MPN B6B-PH-K-S(LF)(SN)
J4: J_PPG; JST_PH_B5B-PH-K_1x05_P2.00mm_Vertical; MPN B5B-PH-K-S(LF)(SN)
J5: J_TEMP; JST_PH_B4B-PH-K_1x04_P2.00mm_Vertical; MPN B4B-PH-K-S(LF)(SN)
J6: J_GSR; JST_PH_B2B-PH-K_1x02_P2.00mm_Vertical; MPN B2B-PH-K-S(LF)(SN)
J7: J_RESP_T; JST_PH_B2B-PH-K_1x02_P2.00mm_Vertical; MPN B2B-PH-K-S(LF)(SN)
J8: J_RESP_A; JST_PH_B2B-PH-K_1x02_P2.00mm_Vertical; MPN B2B-PH-K-S(LF)(SN)
J9: J_BATT_METER; JST_PH_B2B-PH-K_1x02_P2.00mm_Vertical; MPN B2B-PH-K-S(LF)(SN)
L1: 1.5uH; L_Coilcraft_XAL4020-XXX; MPN XAL4020-152MEC
NT1: GND_TIE; GndTie_2mm
Q1, Q4: BSS84; SOT-23; MPN BSS84LT1G
Q2, Q3, Q5: BSS138; SOT-23; MPN BSS138LT1G
R1, R2: 5.1k; R_0603_1608Metric; MPN RC0603FR-075K1L
R3, R15: 0; R_0603_1608Metric; MPN RC0603JR-070RL
R4: 10.0k; R_0603_1608Metric; MPN RC0603FR-0710KL
R5: 15.0k; R_0603_1608Metric; MPN RC0603FR-0715KL
R6, R7: 2.94k 1%; R_0603_1608Metric; MPN RC0603FR-072K94L
R8: 2.2k; R_0603_1608Metric; MPN RC0603FR-072K2L
R9, R10, R11, R12, R19, R20, R21, R30, R31, R32: 100k; R_0603_1608Metric; MPN RC0603FR-07100KL
R13: 49.9k 0.1%; R_0603_1608Metric; MPN RT0603BRD0749K9L
R14: 16.0k 0.1%; R_0603_1608Metric; MPN RT0603BRD0716KL
R16, R17, R40: 1M; R_0603_1608Metric; MPN RC0603FR-071ML
R18: 330k; R_0603_1608Metric; MPN RC0603FR-07330KL
R22, R25, R26, R27, R38: 10k; R_0603_1608Metric; MPN RC0603FR-0710KL
R23, R24: 4.7k; R_0603_1608Metric; MPN RC0603FR-074K7L
R28: 56k 1%; R_0603_1608Metric; MPN RC0603FR-0756KL
R29, R39: 10k 1%; R_0603_1608Metric; MPN RC0603FR-0710KL
R33: 33.2k 1%; R_0603_1608Metric; MPN RC0603FR-0733K2L
R34: 47.5k 1%; R_0603_1608Metric; MPN RC0603FR-0747K5L
R35, R36: 22; R_0603_1608Metric; MPN RC0603FR-0722RL
R37: 46.4k 1%; R_0603_1608Metric; MPN RC0603FR-0746K4L
SW1: DPDT caja; SW_ext_6pad
SW2: BOOT; SW_SPST_B3U-1000P; MPN B3U-1000P
U1: USBLC6-2SC6; SOT-23-6; MPN USBLC6-2SC6
U2: BQ24074; VQFN-16-1EP_3x3mm_P0.5mm_EP1.6x1.6mm; MPN BQ24074RGTR
U3: TPS63070; TPS63070RNM; MPN TPS63070RNMR
U4: TLV75530PDBVR; SOT-23-5; MPN TLV75530PDBVR
U5: ESP32-S3-MINI-1U-N8; ESP32-S2-MINI-1U; MPN ESP32-S3-MINI-1U-N8
U6, U7: ADS122C04; TSSOP-16_4.4x5mm_P0.65mm; MPN ADS122C04IPWR
U8: MCP6004; SOIC-14_3.9x8.7mm_P1.27mm; MPN MCP6004-I/SL

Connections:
/0V5_EXC: R30.1, R31.1, R32.1, U8.1, U8.2 (-)
/3V0_TEMP: C13.1, J5.1, U4.5 (OUT)
/3V3_A: C18.1, C20.1, C22.1, J3.2, J3.6, R15.2, R28.1, U6.6 (AIN3), U6.7 (AIN2), U6.8 (REFN), U6.9 (REFP), U6.10 (AIN1), U6.12 (AVDD), U7.6 (AIN3), U7.8 (REFN), U7.9 (REFP), U7.12 (AVDD), U8.4 (V+)
/3V3_SYS: C7.1, C8.1, C9.1, C10.1, C12.1, C16.1, C17.1, C19.1, C21.1, J4.1, Q2.1 (G), Q5.1 (G), R9.2, R10.2, R13.1, R15.1, R19.1, R21.2, R22.2, R23.2, R24.2, R25.2, R26.2, R27.2, R38.2, U3.7 (VOUT), U3.8 (VOUT), U4.1 (IN), U4.3 (EN), U5.3 (3V3), U6.3 (RESET), U6.13 (DVDD), U7.1 (A0), U7.3 (RESET), U7.13 (DVDD)
/AGND: C18.2, C19.2, C20.2, C21.2, C22.2, J3.1, J6.2, J7.2, J8.2, NT1.2, R29.2, R34.2, U6.1 (A0), U6.2 (A1), U6.4 (DGND), U6.5 (AVSS), U7.2 (A1), U7.4 (DGND), U7.5 (AVSS), U8.11 (V-)
/BAT_METER: J9.1, Q4.3 (D)
/BAT_PROT: C3.1, J2.1, Q1.2 (S), Q4.2 (S), R16.2, R40.2, SW1.4 (A), U2.2 (BAT), U2.3 (BAT)
/BAT_SENSE: C14.1, R17.2, R18.1, U5.5 (IO1)
/BOOT: R38.1, SW2.1, U5.4 (IO0)
/CC1: J1.A5 (CC1), R1.1
/CC2: J1.B5 (CC2), R2.1
/CHG: R9.1, U2.9 (~CHG)
/DIV_EXC: R28.2, R29.1, U8.3 (+)
/DIV_IN: Q1.3 (D), R17.1
/DRDY_ECG: R26.1, U5.10 (IO6), U6.14 (DRDY)
/DRDY_SLOW: R27.1, U5.11 (IO7), U7.14 (DRDY)
/ECG_DIV: R33.2, R34.1, U6.11 (AIN0)
/ECG_OUT: J3.3, R33.1
/EN2_CE: R11.1, SW1.2 (B), U2.4 (~CE), U2.5 (EN2)
/EN_MOD: C15.1, R22.1, U5.45 (EN)
/FB: R13.2, R14.1, U3.5 (FB)
/GND: C1.2, C2.2, C3.2, C4.2, C5.2, C6.2, C7.2, C8.2, C9.2, C10.2, C11.2, C12.2, C13.2, C14.2, C15.2, C16.2, C17.2, D1.1 (A), J1.A1 (GND), J1.A12 (GND), J1.B1 (GND), J1.B12 (GND), J1.S1 (SHIELD), J2.2, J4.2, J5.2, J9.2, NT1.1, Q2.2 (S), Q3.2 (S), Q5.2 (S), R1.2, R2.2, R5.2, R6.2, R7.2, R8.2, R11.2, R12.2, R14.2, R18.2, R19.2, R37.2, SW1.3 (C), SW2.2, U1.2 (GND), U2.8 (VSS), U2.17 (VSS), U3.1 (PS/SYNC), U3.4 (GND), U3.6 (FB2), U3.10 (PGND), U3.15 (VSEL), U4.2 (GND), U5.1 (GND), U5.2 (GND), U5.42 (GND), U5.43 (GND), U5.46 (GND), U5.47 (GND), U5.48 (GND), U5.49 (GND), U5.50 (GND), U5.51 (GND), U5.52 (GND), U5.53 (GND), U5.54 (GND), U5.55 (GND), U5.56 (GND), U5.57 (GND), U5.58 (GND), U5.59 (GND), U5.60 (GND), U5.61 (GND), U5.62 (GND), U5.63 (GND), U5.64 (GND), U5.65 (GND)
/ILIM: R8.1, U2.12 (ILIM)
/ISET: R6.1, U2.16 (ISET)
/ITERM: R7.1, U2.15 (ITERM)
/LO_N: J3.4, U5.16 (IO12)
/LO_P: J3.5, U5.15 (IO11)
/METER_GATE: Q4.1 (G), Q5.3 (D), R40.1
/OUT_AB: U7.7 (AIN2), U8.13 (-), U8.14
/OUT_GSR: U7.11 (AIN0), U8.6 (-), U8.7
/OUT_TH: U7.10 (AIN1), U8.8, U8.9 (-)
/PGOOD: R10.1, U2.7 (~PGOOD)
/PPG_INT: J4.5, R25.1, U5.14 (IO10)
/Q1G: Q1.1 (G), Q2.3 (D), R16.1
/SCL_ADC: R24.1, U5.9 (IO5), U6.16 (SCL), U7.16 (SCL)
/SCL_MOD: J4.3, J5.4, U5.13 (IO9)
/SDA_ADC: R23.1, U5.8 (IO4), U6.15 (SDA), U7.15 (SDA)
/SDA_MOD: J4.4, J5.3, U5.12 (IO8)
/SNS_AB: J8.1, R32.2, U8.12 (+)
/SNS_GSR: J6.1, R30.2, U8.5 (+)
/SNS_TH: J7.1, R31.2, U8.10 (+)
/SW_L1: L1.1, U3.11 (L1)
/SW_L2: L1.2, U3.9 (L2)
/SYS: C2.1, C4.1, C5.1, C6.1, U2.10 (OUT), U2.11 (OUT), U3.12 (VIN), U3.13 (VIN)
/TMR: R37.1, U2.14 (TMR)
/TPS_EN: R12.1, R39.1, SW1.5 (B)
/TPS_EN_IC: R39.2, U3.14 (EN)
/TS: J2.3, U2.1 (TS)
/USB_DM: R35.1, U1.6 (I/O1)
/USB_DM_C: J1.A7 (D-), J1.B7 (D-), U1.1 (I/O1)
/USB_DM_IO: R35.2, U5.23 (USB_D-)
/USB_DP: R36.1, U1.4 (I/O2)
/USB_DP_C: J1.A6 (D+), J1.B6 (D+), U1.3 (I/O2)
/USB_DP_IO: R36.2, U5.24 (USB_D+)
/VAUX: C11.1, U3.3 (VAUX)
/VBUS: J1.A4 (VBUS), J1.A9 (VBUS), J1.B4 (VBUS), J1.B9 (VBUS), R3.1, R4.1, U1.5 (VBUS)
/VBUS_G: Q3.1 (G), R20.2
/VBUS_N: Q3.3 (D), R21.1, U5.6 (IO2)
/VBUS_RAW: C1.1, R3.2, U2.13 (IN)
/VLOG: D1.3 (K), R4.2, R5.1, R20.1, SW1.1 (A), SW1.6 (C), U2.6 (EN1)

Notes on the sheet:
PinaBio "Paca" v2.0. SPEC-0.9. Sensores sin corte en serie. Interruptor de caja C&K 7201SYZQE, DPDT ON-ON, cable 1:1. ON (lejos de la chaveta) cierra 2-1 y 5-4: EN2_CE a VLOG y TPS_EN a BAT_PROT. OFF (hacia la chaveta) cierra 2-3 y 5-6: EN2_CE a GND y TPS_EN a VLOG. Comunes en terminales 2 y 5. L1 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

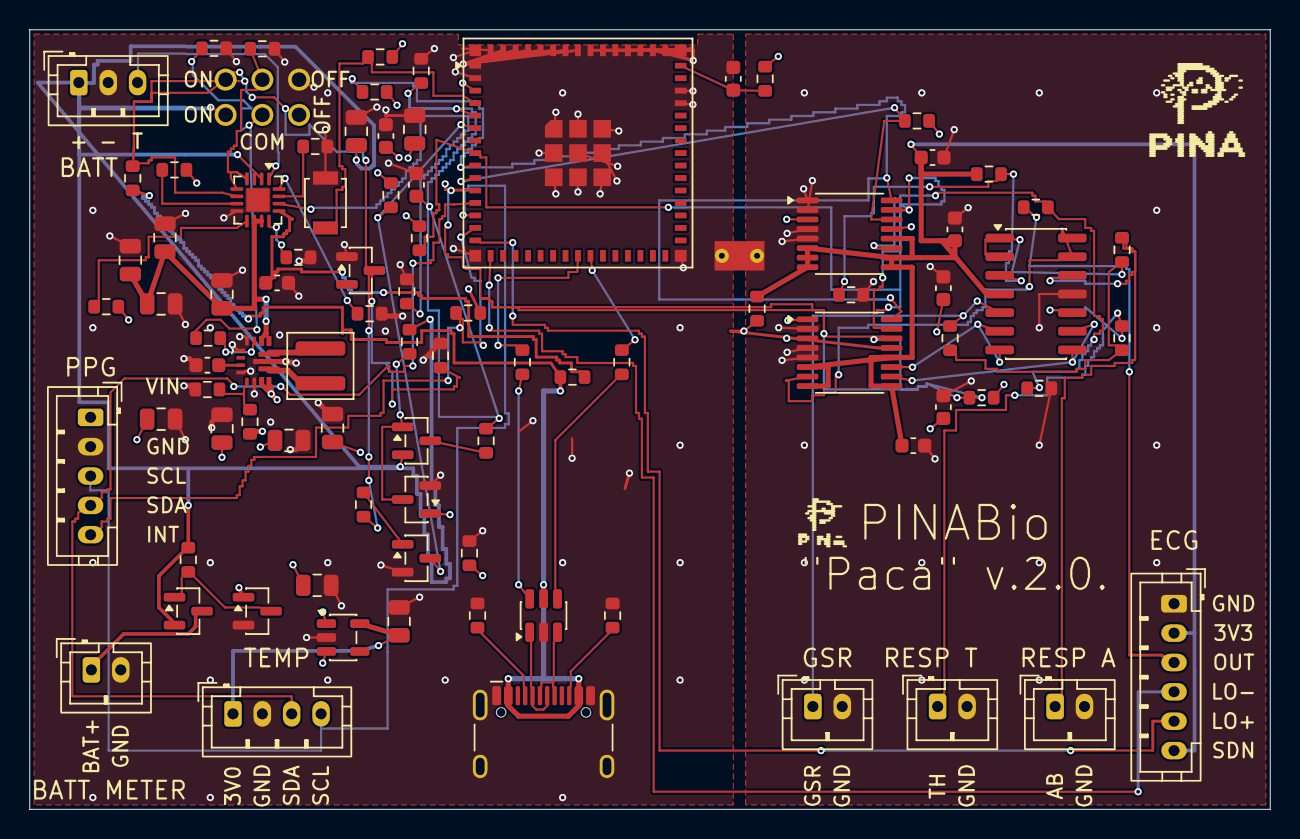
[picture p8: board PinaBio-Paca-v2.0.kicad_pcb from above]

Board: 4 copper layers, 84.5 x 53.1 mm, 89 parts (0 on the bottom side), 60 nets.

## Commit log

2026-09-30 Specify BQ24074 control-pin voltage limits
2026-09-30 Set two regulators and the ECG divider
    The TPS63070 stays at 3.295 V for the board. A TLV75530 makes 3.0 V only for the CJMCU-30205. The ECG divider is 33.2 kΩ and 47.5 kΩ so a 3.4 V AD8232 output stays under the 2.048 V ADC reference.
2026-09-30 Match the TLV75530 capacitors to 2.2 µF
    The temperature LDO is the TLV75530PDBVR, with 2.2 µF X7R at input and output so at least 0.47 µF remains effective. The ECG divider stays 33.2 kΩ and 47.5 kΩ.
2026-09-30 Remove sensor cutoff contacts from V2 specification
2026-10-01 Add the Cursor KiCad 9 board for PinaBio v.2.0
    Schematic, PCB, BOM and fabrication outputs for PinaBio v.2.0. Cursor, on top of SPEC-0.8. Sensor connectors have no series cutoff.
    [PinaBio-v2.0-Cursor-B_Cu.gbl, PinaBio-v2.0-Cursor-B_Mask.gbs, PinaBio-v2.0-Cursor-B_Paste.gbp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]
2026-10-01 Add PinaBio v2.0 ChatGPT KiCad engineering prototype
    [ESP32-S3-MINI-1U.STEP, PinaBio-v2.0-ChatGPT-BOM-grouped.csv, PinaBio-v2.0-ChatGPT-BOM.csv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]
2026-10-01 Document SPEC-0.9 USB protection, split ground and the U.FL keepout
    SPEC-0.9 and PWR-0.7, in Spanish and English, add the 22 ohm USB series
    resistors, the USBLC6-2SC6 in SOT-23-6, the 46.4 kohm TMR resistor, the
    GPIO0 pull-up, the 0805 input and output capacitors, the antenna keepout
    and the single join between digital and analogue ground.
2026-10-01 Update the Cursor KiCad board to SPEC-0.9
    Place the ESP32-S3-MINI-1U U.FL end on the board edge with a copper
    keepout, split digital and analogue ground through one wide net tie, and
    keep the six electrical changes. ERC and DRC are clean and the fab outputs
    are regenerated.
    [PinaBio-v2.0-Cursor-B_Cu.gbl, PinaBio-v2.0-Cursor-B_Mask.gbs, PinaBio-v2.0-Cursor-B_Paste.gbp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]
2026-10-01 Add a top view of the Cursor board
2026-10-02 Revise ChatGPT KiCad PCB with four-layer ground and power planes
    [PinaBio-v2.0-ChatGPT.kicad_pcb]
2026-10-02 Remove superseded ChatGPT CAD reports and preview
2026-10-02 Add connector labels, the PINA logo and the Paca name on the Cursor board silk.
    [PinaBio-v2.0-Cursor.kicad_pcb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]
2026-10-02 Fix mirrored TPS63070 footprint (TI 4222000/B), reroute the TPS63070 zone, portable library tables
    U3 pin 1 is now top left with counter-clockwise numbering, pads 9-11 use the TI sizes, L1 sits east of U3 with both switch nodes on F.Cu without vias. fp-lib-table and sym-lib-table use KIPRJMOD and KICAD9_SYMBOL_DIR. ERC, DRC, fab, position, netlist and render regenerated.
    [PinaBio-v2.0-Cursor-B_Cu.gbl, PinaBio-v2.0-Cursor-B_Mask.gbs, PinaBio-v2.0-Cursor-B_Paste.gbp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]
2026-10-02 Show the board picture at the top of the Cursor board README
2026-10-02 J5 (J_TEMP) pasa a 4 pines: 3V0_TEMP, GND, SDA_MOD, SCL_MOD; se quitan OS y TP1
    JST PH B4B-PH-K en esquema, PCB, BOM, position.csv y pinabio.net. A0, A1 y A2 del CJMCU-30205 van a GND en el modulo; OS queda sin conectar. Gerbers, pcb-top.png, ERC y DRC regenerados; spec ES/EN y 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
    [PinaBio-v2.0-Cursor-B_Cu.gbl, PinaBio-v2.0-Cursor-B_Mask.gbs, PinaBio-v2.0-Cursor-B_Paste.gbp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]
2026-10-02 Add the three pending tasks next to the board picture
2026-10-02 Put the three pending tasks also at the repository root and under the board picture
2026-10-02 Add purchasable BOM fields and schematic-PCB parity
    Symbols and bom.csv now carry manufacturer and MPN, and capacitors
    carry voltage and dielectric. Footprints keep the library nickname and
    unconnected pads use the schematic net name. Electrical values, tracks
    and copper are unchanged.
    [PinaBio-v2.0-Cursor.kicad_pcb, PinaBio-v2.0-Cursor.kicad_sch, bom.csv]
2026-10-02 Compare the module photos with the board connectors
2026-10-02 Record the sensor harness wiring and leave the board pin order
2026-10-02 Dejar el DPDT en la caja y fijar la bobina XAL4020
    Seis taladros conservan las redes del interruptor, con ON, OFF y COM en la serigrafía. La pieza de caja es el C&K 7201SYZQE. L1 queda como Coilcraft XAL4020-152ME. La masa del TPS63070 no se mueve.
    [PinaBio-v2.0-Cursor-B_Cu.gbl, PinaBio-v2.0-Cursor-B_Mask.gbs, PinaBio-v2.0-Cursor-B_Paste.gbp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]
2026-10-02 Explicar los pines del conector de batería
2026-10-02 Complete PinaBio Paca v2 ChatGPT KiCad 9 prototype
    [PinaBio-v2.0-ChatGPT-BOM-grouped.csv, PinaBio-v2.0-ChatGPT-BOM.csv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]
2026-10-02 Refine PINA logo and board title spacing
    [PinaBio-v2.0-ChatGPT-B_Cu.gbl, PinaBio-v2.0-ChatGPT-B_Mask.gbs, PinaBio-v2.0-ChatGPT-B_Paste.gbp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]
2026-10-02 Refine ChatGPT board silkscreen and fabrication outputs
    [PinaBio-v2.0-ChatGPT-B_Cu.gbl, PinaBio-v2.0-ChatGPT-B_Mask.gbs, PinaBio-v2.0-ChatGPT-B_Paste.gbp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]
2026-10-06 Publicar el árbol oficial PinaBio Paca v2.0
    Copia el KiCad revisado a hardware/PinaBio-Paca-v2.0 con nombres sin ChatGPT
    ni Cursor, apunta los README a esa carpeta (foto de la placa al inicio) y
    quita esas menciones de la especificación y de alimentación USB.
    [ESP32-S3-MINI-1U.STEP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]
2026-10-06 Remove Cursor KiCad after official Paca v2.0 tree is on GitHub
    Keep hardware/PinaBio-v2.0-ChatGPT until that copy is no longer needed.
    [PinaBio-v2.0-Cursor-B_Cu.gbl, PinaBio-v2.0-Cursor-B_Mask.gbs, PinaBio-v2.0-Cursor-B_Paste.gbp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]
